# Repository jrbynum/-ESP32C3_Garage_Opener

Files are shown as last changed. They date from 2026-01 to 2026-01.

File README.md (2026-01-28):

# Secure ESP32-C3 Garage Door System

A dual-channel, secure, and web-managed garage door opener system built on the Seeed Studio XIAO ESP32C3. It features a master actuator unit with an OLED display and a low-power, deep-sleeping remote controller.

## 📂 Project Structure

*   **`ESP32C3_Garage_Actuator/`**: Source code for the main unit installed in the garage.
*   **`ESP32C3_Garage_Controller/`**: Source code for the battery-powered remote, plus STL files for the 3D-printed case.
*   **`Garage_Door_Instructable/`**: Additional documentation and diagrams.

---

## 🛠️ Hardware Architecture

### 1. Actuator (Master Unit)
*   **Role:** Controls relays, hosts the Web UI (`192.168.4.1`), and manages the authorized user list (whitelist).
*   **Key Components:**
    *   ESP32-C3 (XIAO)
    *   SSD1306 OLED (I2C)
    *   2x Relays (Active High/Low configurable)

**Wiring Diagram:**
```text
                         +----------------------+
                         |  SEEED XIAO ESP32C3  |
    [5V PSU]------------>| 5V                   |
      |     +----------->| GND                  |
      |     |            |                      |
      |     |      +---->| D1 (GPIO 3) ---------------------> RELAY 1 (Door 1)
      |     |      |     |                      |
      |     |      |   +>| D2 (GPIO 4) ---------------------> RELAY 2 (Door 2)
      |     |      |   | |                      |
      |     |      |   | | D4 (GPIO 6) ---------------------> OLED SDA
      |     |      |   | |                      |
      |     |      |   | | D5 (GPIO 7) ---------------------> OLED SCL
      |     |      |   | |                      |
      |     |      |   | | 3V3 -----------------------------> OLED VCC
      |     |      |   | +----------------------+
      |     |      |   |
      |     |      +----------------------------------------[RELAY MODULES]
      +--------------------------------------------------> GND (Common)
```

### 2. Controller (Remote Unit)
*   **Role:** Wakes up on button press, broadcasts a secure auth token via BLE, and immediately sleeps.
*   **Key Components:**
    *   ESP32-C3 (XIAO)
    *   Momentary Button
    *   LiPo Battery or Coin Cell

**Wiring Diagram:**
```text
                         +----------------------+
                         |  SEEED XIAO ESP32C3  |
    [BATTERY +]--------->| 3V3 / BAT            |
                         |                      |
    [BATTERY -]--+------>| GND                  |
                 |       |                      |
                 |     +>| D0 (GPIO 2)          |
                 |     | +----------------------+
                 |     |
             [BUTTON]  |
                 |     |
                 +-----+
```

---

## 💻 Code Walkthrough

### Actuator (`ESP32C3_Garage_Actuator.ino`)
The system acts as a **BLE Server** and a **WiFi Access Point**.

1.  **Security (Whitelist):**
    *   It maintains a persistent list of allowed MAC addresses in `Preferences` (Flash memory).
    *   Each MAC is assigned a permission level: `1` (Door 1), `2` (Door 2), or `3` (Both).
2.  **BLE Handler:**
    *   Listens for write requests to a specific Characteristic UUID.
    *   Extracts the MAC address from the payload (`0x01` + `MAC`).
    *   Checks the whitelist. If authorized, it triggers the corresponding relay.
3.  **Web Interface:**
    *   Hosted at `http://192.168.4.1` (SSID: `Garage_Master`).
    *   **Dashboard:** Shows the last unauthorized MAC address scan.
    *   **Enrollment:** Allows the admin to assign that unauthorized MAC to a specific door with one click.

### Controller (`ESP32C3_Garage_Controller.ino`)
The remote is designed for extreme power efficiency.

1.  **Deep Sleep:** The CPU is powered down 99.9% of the time.
2.  **Wake-up:** Triggered only when **GPIO 2** is pulled LOW (Button Press).
3.  **Fast Scan & Connect:**
    *   Upon wake-up, it aggressively scans for the `Garage-Master` BLE service.
    *   Connects -> Sends Command (`0x01` + its own MAC) -> Disconnects.
    *   Entire process typically takes <2 seconds before returning to sleep.

---

## 🚀 How to Use

### 1. Installation
1.  **Actuator:** Connect the Relay NO/COM ports to your garage door opener's wall-button terminals. Power the ESP32 via USB.
2.  **Remote:** Assemble the remote in the 3D-printed case (`.stl` files provided). Ensure the battery is charged.

### 2. First-Time Setup
1.  Power on the **Actuator**.
2.  On your phone/PC, connect to WiFi **`Garage_Master`** (Pass: `admin123`).
3.  Go to **`http://192.168.4.1`**.

### 3. Pairing a Remote
1.  **Press the button** on your new Remote. It won't work yet, but the Master will see it.
2.  Refresh the Web UI on your phone.
3.  Under **"Recent Scan"**, you will see the Remote's MAC address.
4.  Click **"Assign to Door 1"** (or Door 2).
5.  **Done!** Press the remote button again to test.

---

## 🖨️ 3D Printing
STL files for the remote enclosure are located in the `ESP32C3_Garage_Controller` folder:
*   `Garage Remote Enclosure.stl` (Base)
*   `Garage Remote Enclosure Lid.stl` (Snap-fit lid)

**Recommended Settings:**
*   Material: PLA or PETG
*   Layer Height: 0.2mm
*   Infill: 20%
*   Supports: None required

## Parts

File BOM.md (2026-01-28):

# Bill of Materials (BOM) & Part Selection

## 🔋 Recommended Battery for Controller

For the **Seeed Studio XIAO ESP32C3**, the **highly recommended** battery is a **3.7V Single-Cell (1S) LiPo Battery**.

### Why not a Coin Cell (CR2032)?
While the ESP32-C3 is efficient, WiFi/BLE transmission creates short current spikes (~150mA-300mA). A standard CR2032 coin cell has high internal resistance and can drop the voltage too low during these spikes, causing the chip to reset ("brownout").
*   **Recommendation:** Use a small LiPo. The XIAO ESP32C3 has **built-in battery charging** capabilities via the USB-C port, making this the easiest and most reliable option.

### Specific Battery Specs
*   **Type:** Lithium Polymer (LiPo)
*   **Voltage:** 3.7V Nominal (4.2V Max)
*   **Capacity:** 150mAh to 400mAh (Trade-off between size and runtime).
*   **Size (Max Dimensions for Case):**
    *   Ideally approx **30mm x 20mm x 6mm** to fit comfortably in a small enclosure.
    *   Common standard sizes: **502030** (300mAh) or **402025** (150mAh).
*   **Connector:** JST-PH 2.0mm (standard) or bare wires (solder directly to XIAO battery pads on the back).

---

## 🛒 EasyEDA / LCSC Compatible Parts List

This list includes both the **Modules** (for assembling with wires) and the **Discrete Components** (if you decide to design a custom PCB carrier board in EasyEDA).

### 1. Actuator (Master Unit)

| Component | Description | Quantity | LCSC Part # (for PCB Design) | Notes |
| :--- | :--- | :--- | :--- | :--- |
| **Microcontroller** | Seeed Studio XIAO ESP32C3 | 1 | *Module* | Search "XIAO ESP32C3" on Digikey/Mouser |
| **OLED Display** | 0.96" SSD1306 I2C (128x64) | 1 | *Module* | Standard 4-pin header pinout (GND, VCC, SCL, SDA) |
| **Relay** | 5V Relay (SRD-05VDC-SL-C) | 2 | **C3790** | Most common relay component |
| **Relay Driver** | NPN Transistor (2N2222 or S8050) | 2 | **C11853** (S8050) | Required if driving raw relay from MCU |
| **Flyback Diode** | 1N4148 (Protection for Relay) | 2 | **C81598** | Place across relay coil |
| **Terminal Block** | 2-Pin Screw Terminal (5.08mm) | 2 | **C8425** | For connecting garage wires |
| **Resistor** | 1kΩ (Base Resistor for Transistor) | 2 | **C17513** (0603 SMD) | |
| **Buck Converter** | 12V/24V to 5V (MP1584 or LM2596) | 1 | *Module* | Optional: To power from Garage Opener's 12V/24V line |

### 2. Controller (Remote Unit)

| Component | Description | Quantity | LCSC Part # (for PCB Design) | Notes |
| :--- | :--- | :--- | :--- | :--- |
| **Microcontroller** | Seeed Studio XIAO ESP32C3 | 1 | *Module* | |
| **Button** | Tactile Switch 6x6x5mm | 1 | **C318884** | Standard through-hole or SMD |
| **Battery Socket** | JST-PH 2.0mm 2-Pin Connector | 1 | **C137171** | Optional: To make battery removable |
| **Slide Switch** | SPDT Slide Switch (Power Cutoff) | 1 | **C29079** | Optional: To turn off remote completely |

### 3. PCB Carrier Board (Optional Design)
If you design a PCB in EasyEDA to hold the XIAO, Relays, and Terminals, use these footprints:

*   **XIAO Headers:** 1x7 2.54mm Female Header (**C2255**) - You need 2 rows.
*   **OLED Header:** 1x4 2.54mm Female Header (**C2255**).
*   **Mounting Holes:** M2 or M3 screw holes for the enclosure.

---

## 🔌 Connection Summary for BOM

### Actuator Wiring
*   **XIAO 5V** -> Relay VCC & OLED VCC
*   **XIAO GND** -> Relay GND & OLED GND
*   **XIAO D1** -> Relay 1 IN
*   **XIAO D2** -> Relay 2 IN
*   **XIAO D4** -> OLED SDA
*   **XIAO D5** -> OLED SCL

### Controller Wiring
*   **Battery +** -> XIAO BAT+ (Solder pad on back)
*   **Battery -** -> XIAO BAT- (Solder pad on back)
*   **Button** -> Pin D0 (GPIO 2) to GND

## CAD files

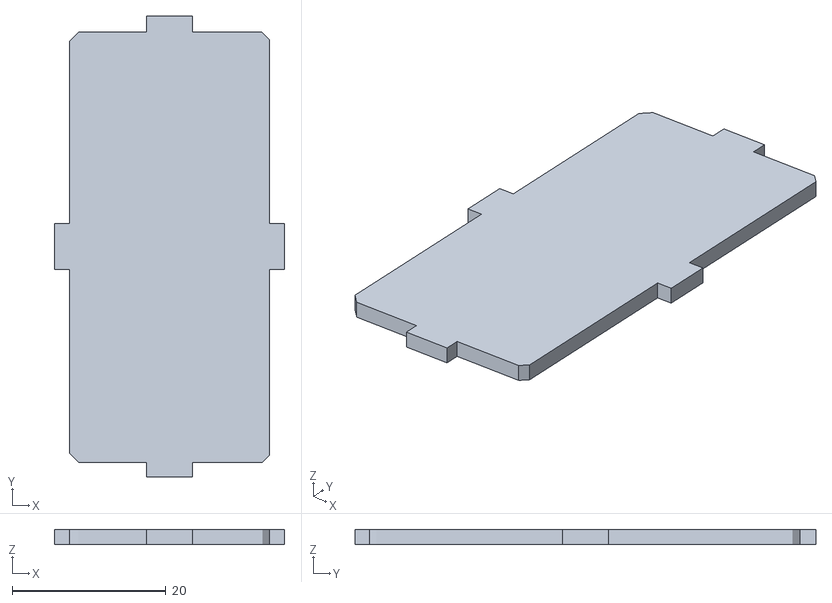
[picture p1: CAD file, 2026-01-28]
ESP32C3_Garage_Controller/Garage Remote Enclosure Lid.stl
30.0 x 60.0 x 2.00

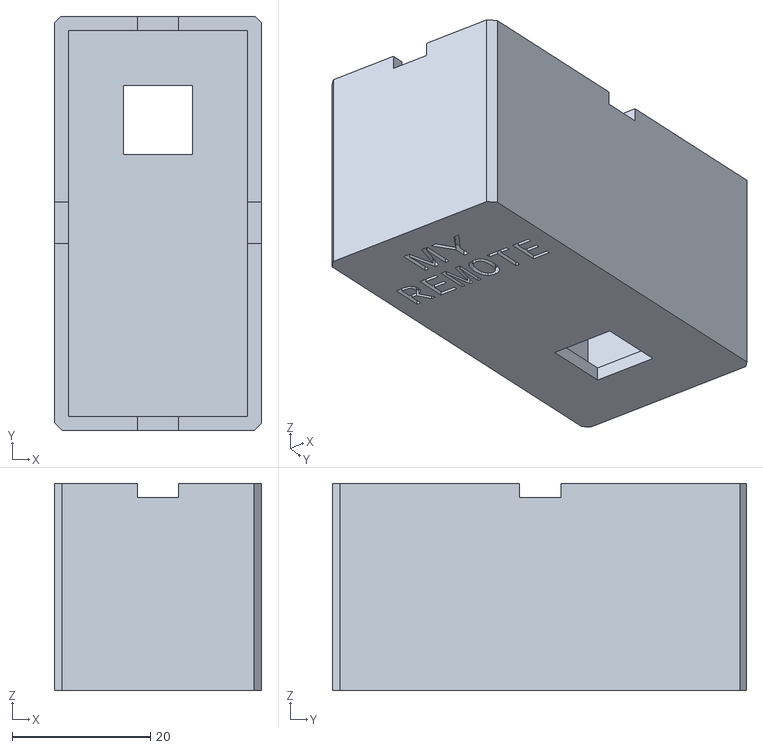
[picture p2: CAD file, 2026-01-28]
ESP32C3_Garage_Controller/Garage Remote Enclosure.stl
30.0 x 60.0 x 30.0

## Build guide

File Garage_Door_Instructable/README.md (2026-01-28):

# Secure Dual-Channel Garage Door Opener (ESP32-C3)

## Project Overview
This project allows you to build a secure, Bluetooth Low Energy (BLE) based garage door opener system. It consists of two parts:
1.  **The Actuator (Master):** Installed in your garage, physically connected to your garage door opener motor(s). It hosts a WiFi access point for configuration and listens for BLE signals.
2.  **The Controller (Remote):** A small, battery-powered remote that you keep in your car. It wakes up only when the button is pressed, sends a secure signal, and goes back to sleep.

## Key Features
*   **Dual Channel:** Control up to two separate garage doors.
*   **Secure Pairing:** Remotes must be explicitly authorized via a Web Interface.
*   **OLED Display:** The Master unit shows real-time status and IP address.
*   **Low Power Remote:** The remote uses Deep Sleep, lasting months on a battery.
*   **Web Management:** Manage paired remotes via a simple web page hosted on the Master.

---

## Bill of Materials (BoM)

### Master Unit (Actuator)
*   1x **Seeed Studio XIAO ESP32C3**
*   2x **Relay Modules** (5V or 3.3V, compatible with microcontroller logic)
*   1x **SSD1306 OLED Display** (0.96" I2C)
*   1x **5V USB Power Supply** (e.g., old phone charger)
*   Connecting wires / Breadboard / PCB

### Remote Unit (Controller)
*   1x **Seeed Studio XIAO ESP32C3**
*   1x **Momentary Push Button**
*   1x **Battery** (3.7V LiPo recommended for stability, or Coin Cell if capable of high peak current)
*   **3D Printed Case:** Files `Garage Remote Enclosure.stl` and `Garage Remote Enclosure Lid.stl` located in `../ESP32C3_Garage_Controller/`.

---

## Assembly Instructions

**See `Wiring_Diagram.txt` in this folder for a visual guide.**

### 1. Wiring the Master
1.  **Relays:**
    *   Connect **Relay 1 Control** to Pin **D1 (GPIO 3)**.
    *   Connect **Relay 2 Control** to Pin **D2 (GPIO 4)**.
    *   Connect VCC/GND appropriate for your relay module.
2.  **OLED Display:**
    *   Connect **SDA** to Pin **D4 (GPIO 6)**.
    *   Connect **SCL** to Pin **D5 (GPIO 7)**.
    *   Connect VCC to 3.3V and GND to GND.
3.  **Garage Door Motor:**
    *   Connect the **Common (COM)** and **Normally Open (NO)** terminals of the Relay to the "Push Button" terminals on your Garage Door Opener motor.

### 2. Wiring the Remote
1.  **Button:**
    *   Connect one leg of the button to **D0 (GPIO 2)**.
    *   Connect the other leg to **GND**.
2.  **Battery:**
    *   Connect battery to the BAT/GND pads (underneath) or 5V/GND pins if using a booster.

---

## Software Installation

### Prerequisites
*   Arduino IDE (Legacy or 2.0+)
*   **Board Package:** `esp32` by Espressif Systems.
*   **Libraries:** 
    *   `Adafruit_GFX`
    *   `Adafruit_SSD1306`

### Flashing the Master
1.  Open `../ESP32C3_Garage_Actuator/ESP32C3_Garage_Actuator.ino`.
2.  Select Board: **Seeed XIAO ESP32C3**.
3.  Connect the Master unit via USB.
4.  Upload the code.
5.  *Note:* The OLED should light up and show "Garage Master" and "IP: 192.168.4.1".

### Flashing the Remote
1.  Open `../ESP32C3_Garage_Controller/ESP32C3_Garage_Controller.ino`.
2.  Select Board: **Seeed XIAO ESP32C3**.
3.  Connect the Remote unit via USB.
4.  Upload the code.
5.  *Note:* Open the Serial Monitor immediately after upload to see the "CONTROLLER ID". Write this down if you wish, but the Master will also auto-detect it.

---

## Setup & Pairing Guide

### 1. Initial Power Up
Power on the **Master Unit**. It will create a WiFi Access Point named **`Garage_Master`**.

### 2. Connect to Web Interface
1.  Connect your phone or laptop to the WiFi network `Garage_Master`.
2.  Password: `admin123`.
3.  Open a browser and navigate to `http://192.168.4.1`.

### 3. Pair a New Remote
1.  Press the button on your **Remote Unit**. 
    *   *The remote will wake up, try to connect, fail (because it's not allowed yet), and go back to sleep.*
2.  Look at the **Master Unit's OLED Display** or the **Web Interface**.
    *   The Web Interface will show a "Recent Scan" with a MAC address (e.g., `AA:BB:CC:11:22:33`).
3.  On the Web Interface, click one of the buttons under "Assign to:":
    *   **Door 1:** Remote triggers Relay 1.
    *   **Door 2:** Remote triggers Relay 2.
    *   **Both:** Remote triggers both (useful if you have double doors or lighting).
4.  The remote is now paired!

### 4. Testing
Press the button on the Remote again.
*   **Master Display:** Should show "Remote Added" or "Opening...".
*   **Relay:** You should hear the relay click.

---

## Security & Maintenance
*   **WiFi Password:** You can change the AP password from the Web Interface.
*   **Revoking Access:** Click "Clear All" on the Web Interface to remove all paired remotes.
*   **Battery:** If the remote stops working, check the battery voltage. The remote sleeps 99% of the time, so battery life should be significant.

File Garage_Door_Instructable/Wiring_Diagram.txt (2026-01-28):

================================================================================
                    GARAGE DOOR CONTROLLER (MASTER) - WIRING DIAGRAM
================================================================================

                               +----------------------+
                               |  SEEED XIAO ESP32C3  |
                               |                      |
          +------------------->| 5V                   |
          |                    |                      |
          |   +--------------->| GND                  |
          |   |                |                      |
          |   |      +-------->| D0 (GPIO 2)          |
          |   |      |         |                      |
          |   |      |   +---->| D1 (GPIO 3) ---------------------> RELAY 1 (IN)
          |   |      |   |     |                      |
          |   |      |   |   +>| D2 (GPIO 4) ---------------------> RELAY 2 (IN)
          |   |      |   |   | |                      |
          |   |      |   |   | | D3 (GPIO 5)          |
          |   |      |   |   | |                      |
          |   |      |   |   | | D4 (GPIO 6) ---------------------> OLED SDA
          |   |      |   |   | |                      |
          |   |      |   |   | | D5 (GPIO 7) ---------------------> OLED SCL
          |   |      |   |   | |                      |
          |   |      |   |   | | 3V3 -----------------------------> OLED VCC / RELAY VCC (if 3.3v)
          |   |      |   |   | +----------------------+
          |   |      |   |   |
          |   |      |   |   |
      [5V PSU]|      |   |   |
          |   |      |   |   |
          |   |      |   |   |
          +---|------|---|---|--------------------------------------+
              |      |   |   |                                      |
              |      |   |   +------------------------------------[RELAY 2 MODULE]
              |      |   |                                          |  |
              |      |   +----------------------------------------[RELAY 1 MODULE]
              |      |                                              |  |
              |      +-------------------------------------------(Unused/Optional)
              |
              +--------------------------------------------------> GND (Common)

      NOTES:
      1. Relays: If using 5V relays, power them from the 5V pin, not 3V3.
         Connect Relay GND to Common GND.
      2. OLED: Standard I2C SSD1306 (GND to GND, VCC to 3V3).

================================================================================
                    GARAGE DOOR REMOTE (CLIENT) - WIRING DIAGRAM
================================================================================

                               +----------------------+
                               |  SEEED XIAO ESP32C3  |
                               |                      |
       [BATTERY +]------------>| 3V3 / BAT            |
                               |                      |
       [BATTERY -]----+------->| GND                  |
                      |        |                      |
                      |      +>| D0 (GPIO 2)          |
                      |      | |                      |
                      |      | | ...                  |
                      |      | +----------------------+
                      |      |
                      |  [PUSH BUTTON]
                      |      |
                      +------+

      NOTES:
      1. Button: Connect a momentary push button between D0 (GPIO 2) and GND.
      2. Power: Can be powered by a 3.7V LiPo via the battery pads on the back 
         of the XIAO, or via USB. For coin cell usage (CR2032), ensure voltage 
         is sufficient (ESP32 peaks can be high), though LiPo is recommended.

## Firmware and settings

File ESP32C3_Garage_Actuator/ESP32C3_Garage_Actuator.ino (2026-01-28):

/*
 * ESP32-C3 Garage Door Actuator (Master)
 * 
 * Features:
 * - Controls 2 Garage Doors (Relays).
 * - HS96L03 (SSD1306) OLED Display.
 * - BLE Server & WiFi AP (Garage_Master).
 * - Web UI for MAC-to-Door mapping.
 * 
 * Hardware:
 * - Relay 1: GPIO 3 (D1)
 * - Relay 2: GPIO 4 (D2)
 * - OLED:   GPIO 6 (D4/SDA), GPIO 7 (D5/SCL)
 */

#include <BLEDevice.h>
#include <BLEUtils.h>
#include <BLEServer.h>
#include <WiFi.h>
#include <WebServer.h>
#include <Preferences.h>
#include <Wire.h>
#include <Adafruit_GFX.h>
#include <Adafruit_SSD1306.h>

// Pins
#define RELAY1_PIN 3
#define RELAY2_PIN 4
#define SDA_PIN    6
#define SCL_PIN    7

// Relay Logic (Change these if your relay is Active-Low)
#define RELAY_ON   HIGH
#define RELAY_OFF  LOW

#define RELAY_TRIGGER_MS 500
#define SCREEN_WIDTH 128
#define SCREEN_HEIGHT 64

// BLE UUIDs
#define SERVICE_UUID        "4fafc201-1fb5-459e-8fcc-c5c9c331914b"
#define CHARACTERISTIC_UUID "beb5483e-36e1-4688-b7f5-ea07361b26a8"

// WiFi
const char* AP_SSID = "Garage_Master";
String apPass = "admin123";

// Global Objects
Preferences preferences;
WebServer server(80);
Adafruit_SSD1306 display(SCREEN_WIDTH, SCREEN_HEIGHT, &Wire, -1);

bool deviceConnected = false;
String currentPeerMAC = "";
String lastUnauthorizedMAC = "None";
unsigned long lastWebActionTime = 0;
const unsigned long WEB_LOCKOUT_MS = 4000;

// ... (Existing Storage Variables)

// ======================= CONFIG =======================
void loadWifiConfig() {
    preferences.begin("garage_cfg", true); // Read-only
    String savedPass = preferences.getString("ap_pass", "");
    if (savedPass.length() >= 8) {
        apPass = savedPass;
    }
    preferences.end();
}

void handleSetPass() {
    if (server.hasArg("pass")) {
        String newPass = server.arg("pass");
        if (newPass.length() >= 8) {
            preferences.begin("garage_cfg", false); // Read-write
            preferences.putString("ap_pass", newPass);
            preferences.end();
            
            String html = "<html><body><h2>Password Saved!</h2><p>Rebooting system... Connect with new password.</p></body></html>";
            server.send(200, "text/html", html);
            delay(1000);
            ESP.restart();
        } else {
            server.send(200, "text/html", "<html><body><h2>Error</h2><p>Password must be at least 8 characters.</p><a href='/'>Back</a></body></html>");
        }
    } else {
        server.sendHeader("Location", "/");
        server.send(303);
    }
}
// Simpler: 
// Key: "mac0", Value: "AA:BB..."
// Key: "perm0", Value: 1 (Door1), 2 (Door2), 3 (Both)
String allowedMACs[10];
int    allowedPerms[10];
int    allowedCount = 0;

// Helper: Format MAC
String macToString(esp_bd_addr_t bda) {
    char str[18];
    sprintf(str, "%02X:%02X:%02X:%02X:%02X:%02X",
            bda[0], bda[1], bda[2], bda[3], bda[4], bda[5]);
    return String(str);
}

// ======================= DISPLAY =======================
void updateDisplay(String status, String subStatus = "") {
  display.clearDisplay();
  display.setTextSize(1);
  display.setTextColor(SSD1306_WHITE);
  
  // Header
  display.setCursor(0,0);
  display.print("Garage Master");
  
  display.setCursor(0,10);
  display.print("IP: 192.168.4.1");
  
  display.setCursor(0,25);
  display.setTextSize(2);
  display.print(status);
  
  if(subStatus != "") {
    display.setTextSize(1);
    display.setCursor(0, 50);
    display.print(subStatus);
  }

  display.display();
}

// ======================= DATA MANAGEMENT =======================

void loadWhitelist() {
    preferences.begin("garage_auth", true);
    allowedCount = preferences.getInt("count", 0);
    for (int i = 0; i < allowedCount; i++) {
        String keyM = "mac" + String(i);
        String keyP = "perm" + String(i);
        allowedMACs[i] = preferences.getString(keyM.c_str(), "");
        allowedPerms[i] = preferences.getInt(keyP.c_str(), 0);
    }
    preferences.end();
}

void addMacToWhitelist(String mac, int permission) {
    if (allowedCount >= 10) return;
    
    // Check if exists, update permission if so
    for(int i=0; i<allowedCount; i++) {
      if(allowedMACs[i].equals(mac)) {
         preferences.begin("garage_auth", false); 
         String keyP = "perm" + String(i);
         preferences.putInt(keyP.c_str(), permission);
         allowedPerms[i] = permission;
         preferences.end();
         return;
      }
    }

    allowedMACs[allowedCount] = mac;
    allowedPerms[allowedCount] = permission;
    allowedCount++;

    preferences.begin("garage_auth", false);
    preferences.putInt("count", allowedCount);
    String keyM = "mac" + String(allowedCount - 1);
    String keyP = "perm" + String(allowedCount - 1);
    preferences.putString(keyM.c_str(), mac);
    preferences.putInt(keyP.c_str(), permission);
    preferences.end();
}

void clearWhitelist() {
    preferences.begin("garage_auth", false);
    preferences.clear();
    preferences.end();
    allowedCount = 0;
}

// Returns permission: 0=None, 1=Door1, 2=Door2, 3=Both
int getPermission(String mac) {
    for (int i = 0; i < allowedCount; i++) {
        if (allowedMACs[i].equals(mac)) return allowedPerms[i];
    }
    return 0;
}

// ======================= WEB SERVER =======================

void handleRoot() {
    String html = "<html><head><meta name='viewport' content='width=device-width, initial-scale=1'>";
    html += "<style>body{font-family:sans-serif; padding:10px; background:#222; color:#eee;}";
    html += ".card{background:#333; padding:15px; border-radius:8px; margin-bottom:15px;}";
    html += "button{padding:8px 15px; margin:5px; border:none; border-radius:4px; cursor:pointer;}";
    html += ".btn-1{background:#3498db; color:white;} .btn-2{background:#e67e22; color:white;} .btn-3{background:#9b59b6; color:white;}";
    html += ".btn-big{padding:15px 30px; font-size:1.2em; width:100%; margin-bottom:10px;}";
    html += "ul{list-style:none; padding:0;} li{border-bottom:1px solid #444; padding:8px 0;}";
    html += "</style></head><body>";
    
    html += "<h2>Garage Master</h2>";
    
    // Direct Control
    html += "<div class='card'><h3>Direct Control</h3>";
    html += "<a href='/open?door=1'><button class='btn-1 btn-big'>Open Door 1</button></a>";
    html += "<a href='/open?door=2'><button class='btn-2 btn-big'>Open Door 2</button></a>";
    html += "</div>";

    // Recent Attempt
    html += "<div class='card'><h3>Recent Scan</h3>";
    html += "<p>MAC: <strong>" + lastUnauthorizedMAC + "</strong></p>";
    
    if (lastUnauthorizedMAC != "None") {
         html += "<div>Assign to:</div>";
         html += "<a href='/auth?mac=" + lastUnauthorizedMAC + "&door=1'><button class='btn-1'>Door 1</button></a>";
         html += "<a href='/auth?mac=" + lastUnauthorizedMAC + "&door=2'><button class='btn-2'>Door 2</button></a>";
         html += "<a href='/auth?mac=" + lastUnauthorizedMAC + "&door=3'><button class='btn-3'>Both</button></a>";
    }
    html += "</div>";

    // List
    html += "<div class='card'><h3>Paired Remotes (" + String(allowedCount) + "/10)</h3><ul>";
    for (int i = 0; i < allowedCount; i++) {
        String pStr = (allowedPerms[i] == 1) ? "Door 1" : (allowedPerms[i] == 2) ? "Door 2" : "BOTH";
        html += "<li>" + allowedMACs[i] + " <span style='float:right; color:#aaa'>" + pStr + "</span></li>";
    }
    html += "</ul><br><a href='/clear'><button style='background:#c0392b; color:white'>Clear All</button></a></div>";
    
    // WiFi Settings
    html += "<div class='card'><h3>WiFi Settings</h3>";
    html += "<form action='/setpass' method='POST'>";
    html += "<input type='text' name='pass' placeholder='New Password (min 8 chars)' style='padding:8px; width:70%; margin-right:5px;'>";
    html += "<button class='btn-1' style='background:#555;'>Save</button>";
    html += "</form></div>";
    
    html += "</body></html>";
    server.send(200, "text/html", html);
}

void handleOpen() {
    // Lockout Check
    if (millis() - lastWebActionTime < WEB_LOCKOUT_MS) {
        Serial.println("Web ignored: Lockout active");
        server.sendHeader("Location", "/");
        server.send(303);
        return;
    }
    lastWebActionTime = millis();

    if (server.hasArg("door")) {
        int doorId = server.arg("door").toInt();
        triggerDoor(doorId);
    }
    server.sendHeader("Location", "/");
    server.send(303);
}

void handleAuth() {
    if (server.hasArg("mac") && server.hasArg("door")) {
        addMacToWhitelist(server.arg("mac"), server.arg("door").toInt());
        updateDisplay("Remote Added", server.arg("mac"));
        delay(1000);
        updateDisplay("Ready");
    }
    server.sendHeader("Location", "/");
    server.send(303);
}

void handleClear() {
    clearWhitelist();
    updateDisplay("Memory Cleared");
    delay(1000);
    updateDisplay("Ready");
    server.sendHeader("Location", "/");
    server.send(303);
}

// ======================= CONTROL =======================

void triggerDoor(int doorId) {
    int pin = (doorId == 1) ? RELAY1_PIN : RELAY2_PIN;
    Serial.printf("Triggering Door %d (Pin %d)\n", doorId, pin);
    
    updateDisplay("OPENING...", "Door " + String(doorId));
    
    digitalWrite(pin, RELAY_ON); 
    delay(RELAY_TRIGGER_MS);
    digitalWrite(pin, RELAY_OFF);
    
    updateDisplay("Ready");
}

// ======================= BLE CALLBACKS =======================

class MyServerCallbacks: public BLEServerCallbacks {
    void onConnect(BLEServer* pServer) {
      deviceConnected = true;
      Serial.println("Device Connected (Waiting for Auth Payload...)");
      updateDisplay("Connected", "Verifying...");
    }

    void onDisconnect(BLEServer* pServer) {
      deviceConnected = false;
      Serial.println("Device Disconnected");
      updateDisplay("Ready", "Waiting...");
      pServer->getAdvertising()->start();
    }
};

class MyCallbacks: public BLECharacteristicCallbacks {
    void onWrite(BLECharacteristic *pCharacteristic) {
        String value = pCharacteristic->getValue();
        
        // Expected Protocol: 1 Byte CMD (0x01) + MAC Address String
        // Example: 0x01 + "AA:BB:CC:DD:EE:FF"
        // Min length: 1 + 17 = 18 bytes
        
        if (value.length() >= 18 && value[0] == 0x01) {
            String clientMac = value.substring(1, 18); // Extract "AA:BB..."
            clientMac.toUpperCase(); 
            
            Serial.print("Auth Request from: "); Serial.println(clientMac);
            currentPeerMAC = clientMac; // Store for context

            int perm = getPermission(clientMac);
            
            if (perm > 0) {
                if (perm == 1) triggerDoor(1);
                else if (perm == 2) triggerDoor(2);
                else if (perm == 3) { triggerDoor(1); delay(200); triggerDoor(2); }
            } else {
                Serial.println("Unauthorized");
                lastUnauthorizedMAC = clientMac;
                updateDisplay("Denied!", clientMac);
            }
        } else {
            Serial.println("Invalid Payload Format");
        }
    }
};

// ======================= SETUP & LOOP =======================

void setup() {
    Serial.begin(115200);
    
    // Relays
    pinMode(RELAY1_PIN, OUTPUT);
    pinMode(RELAY2_PIN, OUTPUT);
    digitalWrite(RELAY1_PIN, RELAY_OFF);
    digitalWrite(RELAY2_PIN, RELAY_OFF);

    // OLED
    Wire.begin(SDA_PIN, SCL_PIN);
    if(!display.begin(SSD1306_SWITCHCAPVCC, 0x3C)) { 
        Serial.println(F("SSD1306 allocation failed"));
    }
    display.clearDisplay();
    updateDisplay("Booting...");

    loadWhitelist();
    loadWifiConfig();

    // WiFi AP
    WiFi.softAP(AP_SSID, apPass.c_str());
    
    server.on("/", handleRoot);
    server.on("/open", handleOpen);
    server.on("/auth", handleAuth);
    server.on("/clear", handleClear);
    server.on("/setpass", HTTP_POST, handleSetPass);
    server.begin();

    // BLE
    BLEDevice::init("Garage-Master");
    BLEServer *pServer = BLEDevice::createServer();
    pServer->setCallbacks(new MyServerCallbacks());

    BLEService *pService = pServer->createService(SERVICE_UUID);
    BLECharacteristic *pCharacteristic = pService->createCharacteristic(
                                         CHARACTERISTIC_UUID,
                                         BLECharacteristic::PROPERTY_READ |
                                         BLECharacteristic::PROPERTY_WRITE
                                       );
    pCharacteristic->setCallbacks(new MyCallbacks());
    pService->start();

    BLEAdvertising *pAdvertising = BLEDevice::getAdvertising();
    pAdvertising->addServiceUUID(SERVICE_UUID);
    pAdvertising->setScanResponse(true);
    BLEDevice::startAdvertising();
    
    updateDisplay("Ready", "AP: " + String(AP_SSID));
}

void loop() {
    server.handleClient();
    delay(10); 
}

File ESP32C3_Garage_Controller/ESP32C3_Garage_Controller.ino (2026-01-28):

/*
 * ESP32-C3 Garage Door Controller (Secure Client - Low Power)
 * 
 * Logic:
 * 1. Deep Sleep by default.
 * 2. Wakes on Button Press (GPIO 2, LOW).
 * 3. Scans for Garage-Master.
 * 4. Connects, Sends Trigger, Disconnects.
 * 5. Returns to Deep Sleep.
 * 
 * Hardware: Button on GPIO 2 (D0) to GND.
 */

#include <BLEDevice.h>
#include <BLEUtils.h>
#include <BLEScan.h>
#include <BLEAdvertisedDevice.h>

#define BUTTON_PIN 2
#define SCAN_TIMEOUT_SEC 5
#define TOTAL_TIMEOUT_SEC 10 // Safety cutoff

static BLEUUID serviceUUID("4fafc201-1fb5-459e-8fcc-c5c9c331914b");
static BLEUUID charUUID("beb5483e-36e1-4688-b7f5-ea07361b26a8");

static BLEAdvertisedDevice* myDevice = nullptr;
bool deviceFound = false;

// ===================== SLEEP HELPER =====================
void goToSleep() {
    Serial.println("Entering Deep Sleep...");
    delay(100); // Flush serial
    
    // Configure Wakeup on Button (GPIO 2) LOW
    // Ensure button is wired between GPIO 2 and GND
    pinMode(BUTTON_PIN, INPUT_PULLUP);
    esp_deep_sleep_enable_gpio_wakeup(1ULL << BUTTON_PIN, ESP_GPIO_WAKEUP_GPIO_LOW);
    
    esp_deep_sleep_start();
}

// ===================== BLE CALLBACKS =====================
class MyAdvertisedDeviceCallbacks: public BLEAdvertisedDeviceCallbacks {
  void onResult(BLEAdvertisedDevice advertisedDevice) {
    if (advertisedDevice.haveServiceUUID() && advertisedDevice.isAdvertisingService(serviceUUID)) {
      BLEDevice::getScan()->stop();
      myDevice = new BLEAdvertisedDevice(advertisedDevice);
      deviceFound = true;
    }
  }
};

class MyClientCallback : public BLEClientCallbacks {
  void onConnect(BLEClient* pclient) {}
  void onDisconnect(BLEClient* pclient) {}
};

// ===================== MAIN FLOW =====================
void setup() {
  Serial.begin(115200);
  
  // 1. Identify reason for wakeup
  esp_sleep_wakeup_cause_t cause = esp_sleep_get_wakeup_cause();
  if (cause != ESP_SLEEP_WAKEUP_GPIO) {
      Serial.println("Power On Reset / Not Button Wake.");
      // If it's fresh power-on, we might want to print ID then sleep
      BLEDevice::init("Garage-Controller");
      String myMac = BLEDevice::getAddress().toString().c_str();
      Serial.print("CONTROLLER ID: "); Serial.println(myMac);
      Serial.println("Sleeping in 5s...");
      delay(5000);
      goToSleep();
  }

  Serial.println("Wakeup! Scanning...");
  
  BLEDevice::init("Garage-Controller");
  BLEScan* pBLEScan = BLEDevice::getScan();
  pBLEScan->setAdvertisedDeviceCallbacks(new MyAdvertisedDeviceCallbacks());
  pBLEScan->setInterval(100); // Fast scan
  pBLEScan->setWindow(99);
  pBLEScan->setActiveScan(true);
  
  // 2. Scan
  pBLEScan->start(SCAN_TIMEOUT_SEC, false);
  
  // 3. Connect & Send
  if (deviceFound && myDevice != nullptr) {
      Serial.println("Found Master. Connecting...");
      BLEClient* pClient = BLEDevice::createClient();
      pClient->setClientCallbacks(new MyClientCallback());

      if (pClient->connect(myDevice)) {
          BLERemoteService* pRemoteService = pClient->getService(serviceUUID);
          if (pRemoteService != nullptr) {
                                BLERemoteCharacteristic* pRemoteCharacteristic = pRemoteService->getCharacteristic(charUUID);
                            if (pRemoteCharacteristic != nullptr) {
                                Serial.println("Sending Auth Payload...");
                                
                                // Construct Payload: [0x01] + "AA:BB:CC:DD:EE:FF"
                                String myMac = BLEDevice::getAddress().toString().c_str();
                                String payload = "";
                                payload += (char)0x01; // Command Byte
                                payload += myMac;      // MAC String
                                
                                pRemoteCharacteristic->writeValue(payload.c_str(), payload.length());
                                delay(200); // Ensure transmission
                            }          }
          pClient->disconnect();
      } else {
          Serial.println("Failed to connect.");
      }
  } else {
      Serial.println("Master not found.");
  }

  // 4. Sleep
  goToSleep();
}

void loop() {
  // Empty - Logic is linear in setup()
}

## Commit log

2026-01-28 Initial commit: Garage Door Opener (Actuator, Controller, Docs)
    [Garage Remote Enclosure Lid.stl, Garage Remote Enclosure.stl]
2026-01-28 Add Bill of Materials (BOM) with battery recommendations
